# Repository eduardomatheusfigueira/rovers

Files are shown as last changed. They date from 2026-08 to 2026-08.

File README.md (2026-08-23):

# Rover Frugal 4WD/4WS
## UGV de baixo custo para logística predial — engenharia, simulação e gêmeo digital





> **Missão.** Desenvolver um Veículo Terrestre Não Tripulado capaz de buscar um
> notebook em qualquer ponto do Itaipu Parquetec e entregá-lo no departamento de
> T.I., **subindo escadas**, operado remotamente por um piloto — construído com
> tubos de PVC, impressão 3D, elásticos de escritório e eletrônica de prateleira.

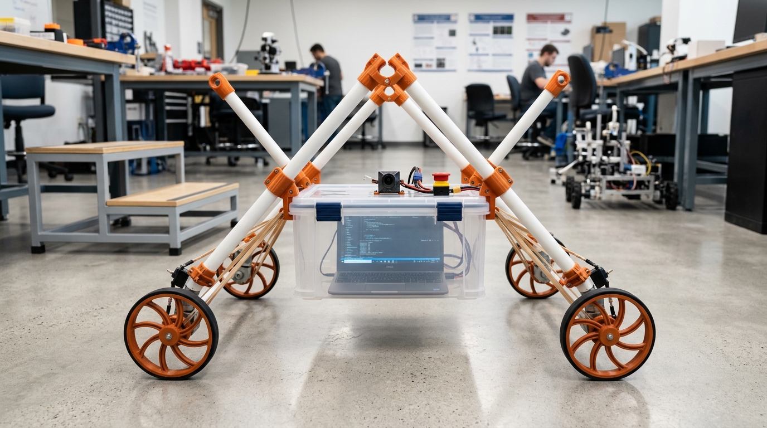
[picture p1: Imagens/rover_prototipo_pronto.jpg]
Protótipo do Rover Frugal


---

## Onde começar

| Se você quer... | Vá para |
| :--- | :--- |
| entender **as decisões de engenharia e por que mudaram** | [Auditoria Técnica R1→R2](00_Especificacao_Mestre/02_Auditoria_Tecnica.md) |
| ver **todos os números do projeto num lugar só** | [Parâmetros Mestres](00_Especificacao_Mestre/00_Parametros_Mestres.md) |
| saber **o que ainda falta provar** | [Requisitos e Rastreabilidade](00_Especificacao_Mestre/01_Requisitos_e_Rastreabilidade.md) |
| **pilotar** o rover num percurso simulado | [Gêmeo digital 3D](#gêmeo-digital-3d) |
| simular **física completa com ROS 2** | [Workspace ROS 2 / Gazebo](#ros-2-e-gazebo) |
| **rodar as contas** você mesmo | [Simulador Python](#simulador-físico-em-python) |
| avaliar a **proposta institucional** | [Pitch ao Parquetec](04_Proposta_Itaipu_Parquetec/01_Pitch_e_Plano_de_Apoio.md) |

---

## Estado do projeto

O projeto está na **Fase 2 — engenharia de detalhe e simulação**. Nenhuma peça
foi fabricada ainda. Isso importa para ler o resto do repositório:

* ✅ **18 requisitos** verificados por análise ou simulação automatizada;
* 🟡 **13 requisitos** verificados em simulação, aguardando ensaio físico;
* ⬜ **14 requisitos** dependem de hardware montado.

Todas as conclusões numéricas aqui são **previsões de modelo**, com domínio de
validade declarado em [Verificação e Validação](03_Simulacao_e_Prototipacao_Digital/04_Verificacao_e_Validacao_do_Modelo.md).

---

## O que a revisão R2 mudou no projeto

A engenharia foi reconstruída sobre uma fonte única de parâmetros e sobre modelos
sem fatores de ajuste. Cinco achados alteraram o projeto físico:

| Achado | R1 | R2 |
| :--- | :--- | :--- |
| **Diâmetro da roda** — a roda precisa alcançar o nariz do degrau seguinte, não apenas rolar | Φ300 mm (critério de rolamento em plano) | **Φ420 mm** por marcha síncrona e robustez de fase |
| **Aro elástico** — sem ele o cubo cai 105 mm por raio em piso plano | "opcional" | **item crítico** |
| **Curso da suspensão** — dimensionado pela energia da queda de cubo | 35 mm (4,2 g na carga) | **90 mm** (0,8 g) |
| **Rigidez do C-STS** — não se copia rigidez entre escalas | 0,55 N·m/rad (do artigo → 674° de deflexão) | **12,30 N·m/rad** por semelhança dimensional |
| **Classificação cinemática** | δm=2, δs=4, δM=3 (soma 6) | **δm=1, δs=2, δM=3** — não holonômico |

E a geração das malhas para o ROS 2 revelou um sétimo: **as rodas Φ420 pesam
2,55 kg, não os 1,80 kg orçados** — a massa total subiu para 10,03 kg e puxou
junto torque de projeto, rigidez do C-STS e margem de tração
([A-21](00_Especificacao_Mestre/02_Auditoria_Tecnica.md#a-21)). Todos os KPIs
continuam atendidos, com menos folga.

Mais dois limites operacionais que ninguém tinha visto:

* o gargalo da escada é **térmico**, não energético: 27 s de subida contínua antes
  do limite do enrolamento — a missão inteira usa só 15% da bateria;
* o rover **não sobe escada molhada**: exige μ ≥ 0,72 e o concreto úmido dá 0,55.

Cada achado está documentado com evidência reproduzível na
[Auditoria Técnica](00_Especificacao_Mestre/02_Auditoria_Tecnica.md).

---

## A ideia central, em uma equação

Uma roda de raios não rola sobre a escada — ela **salta de nariz em nariz**. Para
que o raio seguinte alcance o degrau seguinte:

$$\underbrace{\sqrt{E^2+P^2}}_{\text{passo do degrau}} \;\le\; 2\,r_{max}\sin\!\left(\frac{\pi}{N}\right)$$

Para o degrau de referência (E = 170 mm, P = 300 mm) e N = 3 raios:
**r_max ≥ 199 mm**. A roda de Φ300 mm alcança 260 mm contra 345 mm exigidos — e
por isso trava na face do espelho. A dedução completa está em
[Síntese da Roda](02_Engenharia_e_Arquitetura/06_Sintese_da_Roda_e_Geometria_de_Escalada.md).

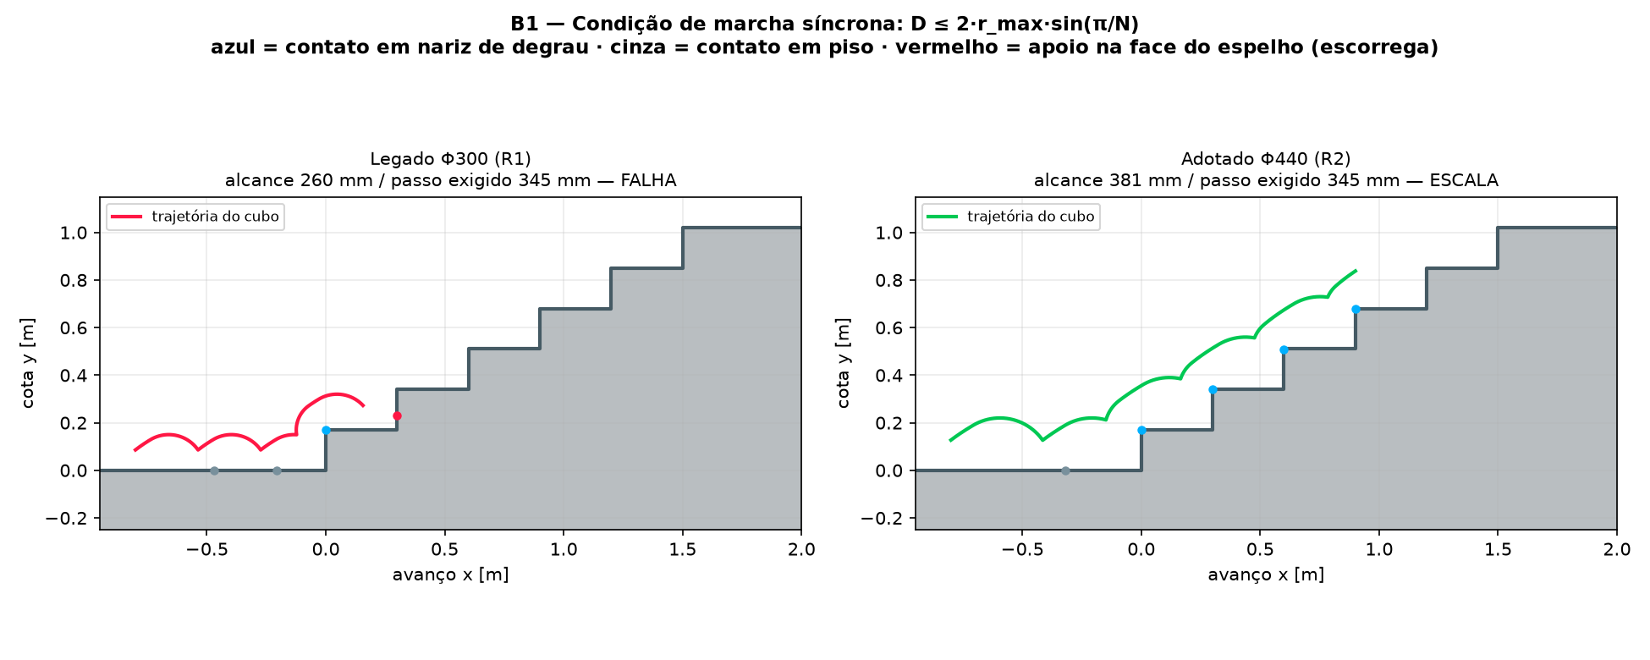
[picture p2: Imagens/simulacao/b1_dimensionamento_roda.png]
Comparação das duas rodas


---

## Como o repositório se sustenta

**Nenhum número de engenharia é digitado duas vezes.** Tudo vive em
[`parametros_mestres.yaml`](00_Especificacao_Mestre/parametros_mestres.yaml):

```
00_Especificacao_Mestre/parametros_mestres.yaml   ← fonte única de verdade
        │
        ├─→ simulador_python/config.py ────────── simulador, benchmarks, relatório
        ├─→ prototipo_3d/parametros.js ────────── gêmeo digital 3D
        └─→ 00_Parametros_Mestres.md ──────────── tabela da documentação
                                                  (os dois últimos são gerados)
```

Mudar o diâmetro da roda no YAML muda o simulador, o modelo 3D e a documentação
ao mesmo tempo. Testes automatizados verificam a coerência a cada alteração.

---

## Simulador físico em Python

```bash
pip install -r requirements.txt

python3 -m simulador_python.main --parametros   # configuração resolvida
python3 -m simulador_python.main --marcha       # marcha na escada de referência
python3 -m simulador_python.main --sintese      # varredura do espaço de projeto
python3 -m simulador_python.main --benchmark    # 6 benchmarks + figuras
python3 -m simulador_python.main --relatorio    # Relatório de Engenharia completo
python3 -m pytest testes/ -q                    # 73 verificações
```

| Módulo | O que resolve |
| :--- | :--- |
| [`geometria_escada.py`](simulador_python/geometria_escada.py) | marcha da roda de raios por **eventos de contato** — o núcleo do projeto |
| [`csts.py`](simulador_python/csts.py) | dimensionamento da mola espiral por semelhança dimensional e modelo de impacto |
| [`kinematics.py`](simulador_python/kinematics.py) | cinemática 4WS e classificação de Siegwart calculada por posto de matriz |
| [`terramechanics.py`](simulador_python/terramechanics.py) | cargas normais, estabilidade e comparação com skid-steer (Wong) |
| [`powertrain.py`](simulador_python/powertrain.py) | motor CC, redutor, bateria, modelo térmico e orçamento de missão |
| [`multibody_dynamics.py`](simulador_python/multibody_dynamics.py) | dinâmica sagital com a carga a bordo, alimentada pela marcha real |
| [`relatorio.py`](simulador_python/relatorio.py) | gera o Relatório de Engenharia — nenhum número é digitado à mão |

---

## Gêmeo digital 3D

Percurso completo de homologação — calçada, meio-fio, rampa, escadaria de 8
degraus, porta estreita e sala da T.I. — com física real de contato dos raios
curvos, C-STS integrada, bateria, modelo térmico e telemetria exportável.

```bash
# opção 1: arquivo único, duplo clique, sem servidor e sem internet
prototipo_3d_standalone.html

# opção 2: versão modular (recomendada para desenvolvimento)
python3 -m http.server 8000
# abrir http://localhost:8000/prototipo_3d/
```

O botão **"Comparar com a roda Φ300 (R1)"** reconstrói o rover com a geometria
original e reproduz a falha do achado A-01 na prática. As chaves de suspensão
ligam e desligam aro, elásticos e C-STS para ver o efeito de cada estágio na
aceleração sentida pelo notebook.

> Three.js r160 está versionado em `prototipo_3d/vendor/` (licença MIT): o
> protótipo **funciona offline**, sem depender de CDN.

---

## ROS 2 e Gazebo

Workspace completo em [`ros2_ws/`](ros2_ws/) — **ROS 2 Jazzy + Gazebo Harmonic**:

```bash
cd ros2_ws && colcon build --symlink-install && source install/setup.bash

ros2 launch rover_frugal_bringup missao.launch.py            # percurso completo
ros2 launch rover_frugal_bringup ensaio_escada.launch.py     # ensaio instrumentado
ros2 launch rover_frugal_description visualizar.launch.py    # só a geometria, no RViz
```

| Pacote | Conteúdo |
| :--- | :--- |
| `rover_frugal_description` | URDF/xacro **sem nenhum número** — lê `config/parametros.yaml`, gerado do arquivo mestre; malhas STL geradas do mesmo perfil de raio da física |
| `rover_frugal_control` | cinemática 4WS, tração com a curva real do motorredutor, molas passivas (suspensão e C-STS), supervisor de segurança |
| `rover_frugal_gazebo` | mundos SDF gerados dos parâmetros, ponte `ros_gz`, launch |
| `rover_frugal_bringup` | missão, ensaios, registrador de telemetria |

Três decisões de modelagem que valem destaque — todas detalhadas em
[`03_Simulacao/05`](03_Simulacao_e_Prototipacao_Digital/05_ROS2_e_Gazebo.md):

* **O casco convexo de uma roda de raios é um disco.** Usar a malha como colisão
  faria o motor de física apagar silenciosamente a geometria de raios — e a
  simulação escalaria escadas que na prática são impossíveis. A colisão é uma
  cadeia de 81 esferas por roda, com sobreposição garantida.
* **O aro elástico não colapsa em corpo rígido**, então o modelo tem duas
  variantes (`aro_elastico:=true|false`) e a limitação é declarada.
* **As molas passivas ficam num nó ROS, não no SDF** — o que as torna portáteis e
  impõe um requisito explícito de 1000 Hz na malha de controle.
* **A tração é comandada por esforço, não por velocidade.** Com interface de
  velocidade o motor simulado teria torque de stall a 1,53 m/s e o rover subiria
  escadas que o motorredutor real não sustenta — a margem de torque de 1,61
  jamais seria exercida pela simulação.

74 testes validam o pacote **sem ROS instalado** (`xacro` e `yourdfpy` do PyPI):
massa, inércias, cinemática direta, limites de junta, geometria de colisão, a
escada do mundo e o passo de integração. A cinemática do nó ROS é comparada com a
do simulador a cada execução — divergência de 8,9 × 10⁻¹⁶ rad, contra os 0,1° que
o ensaio ENS-01 admite.

---

## Mapa da documentação

```mermaid
graph TD
    M["00. Especificação Mestre<br/><i>fonte única de verdade</i>"]
    M --> M1["Parâmetros Mestres<br/><i>gerado</i>"]
    M --> M2["Requisitos e Rastreabilidade"]
    M --> M3["Auditoria Técnica R1→R2"]

    P1["01. Planejamento Geral"] --> P1a["Escopo · Fases · PMBOK 7 · Critérios"]
    P2["02. Engenharia e Arquitetura"] --> P2a["Mecânica · Rodas · 4WD/4WS · Eletrônica"]
    P2 --> P2b["<b>06. Síntese da Roda</b><br/>07. Tração e Térmica<br/>08. Firmware<br/>09. FMEA"]
    P3["03. Simulação"] --> P3a["CAD · Dinâmica · Gêmeo Digital"]
    P3 --> P3b["<b>04. Verificação e Validação</b>"]
    P4["04. Proposta Parquetec"] --> P4a["Pitch · Equipe · Orçamento"]
    P5["05. Execução e Testes"] --> P5a["Montagem · Ensaios · Missão"]
    P6["06. Roadmap Futuro"] --> P6a["Fase A longo alcance · Fase B uso dual"]

    M --> P1 & P2 & P3 & P4 & P5 & P6
```

### Índice

**[00. Especificação Mestre](00_Especificacao_Mestre/)** — fonte única de verdade
* [`parametros_mestres.yaml`](00_Especificacao_Mestre/parametros_mestres.yaml) — todos os números do projeto
* [00. Parâmetros Mestres](00_Especificacao_Mestre/00_Parametros_Mestres.md) *(gerado)* — tabela e verificações de coerência
* [01. Requisitos e Rastreabilidade](00_Especificacao_Mestre/01_Requisitos_e_Rastreabilidade.md) — 45 requisitos com método de verificação
* [02. Auditoria Técnica](00_Especificacao_Mestre/02_Auditoria_Tecnica.md) — 20 achados de R1 com evidência e resolução

**[01. Planejamento Geral](01_Planejamento_Geral/)**
* [01. Visão Geral e Escopo](01_Planejamento_Geral/01_Visao_Geral_e_Escopo.md) · [02. Fases e Cronograma](01_Planejamento_Geral/02_Estrutura_Fases_e_Cronograma.md) · [03. Gestão e PMBOK 7](01_Planejamento_Geral/03_Gestao_e_PMBOK7.md) · [04. Critérios de Sucesso](01_Planejamento_Geral/04_Criterios_de_Sucesso_e_Validacao.md)

**[02. Engenharia e Arquitetura](02_Engenharia_e_Arquitetura/)**
* [01. Arquitetura Mecânica](02_Engenharia_e_Arquitetura/01_Arquitetura_Mecanica_e_Geometria.md) · [02. Rodas e Suspensão](02_Engenharia_e_Arquitetura/02_Rodas_Curved_Spokes_e_Suspensao.md) · [03. Tração 4WD e Direção 4WS](02_Engenharia_e_Arquitetura/03_Tracao_4WD_e_Direcao_4WS.md) · [04. Eletrônica e Potência](02_Engenharia_e_Arquitetura/04_Eletronica_Controle_e_Potencia.md) · [05. Blondel e Colisão](02_Engenharia_e_Arquitetura/05_Dimensionamento_Blondel_e_Dinamica_Colisao.md)
* **[06. Síntese da Roda e Geometria de Escalada](02_Engenharia_e_Arquitetura/06_Sintese_da_Roda_e_Geometria_de_Escalada.md)** — documento central de R2
* **[07. Tração, Energia e Térmica](02_Engenharia_e_Arquitetura/07_Orcamento_de_Tracao_Energia_e_Termica.md)**
* **[08. Firmware e Segurança Funcional](02_Engenharia_e_Arquitetura/08_Arquitetura_de_Firmware_e_Seguranca_Funcional.md)**
* **[09. FMEA](02_Engenharia_e_Arquitetura/09_FMEA_e_Analise_de_Falhas.md)**

**[03. Simulação e Prototipação Digital](03_Simulacao_e_Prototipacao_Digital/)**
* [01. Modelagem CAD 3D](03_Simulacao_e_Prototipacao_Digital/01_Plano_de_Modelagem_CAD_3D.md) · [02. Simulação Dinâmica](03_Simulacao_e_Prototipacao_Digital/02_Simulacao_Dinamica_e_Controle.md) · [03. Gêmeo Digital](03_Simulacao_e_Prototipacao_Digital/03_Ambiente_Virtual_e_Digital_Twin.md)
* **[04. Verificação e Validação do Modelo](03_Simulacao_e_Prototipacao_Digital/04_Verificacao_e_Validacao_do_Modelo.md)**
* **[05. Simulação Multicorpo em ROS 2 e Gazebo](03_Simulacao_e_Prototipacao_Digital/05_ROS2_e_Gazebo.md)**

**[04. Proposta Itaipu Parquetec](04_Proposta_Itaipu_Parquetec/)**
* [01. Pitch e Plano de Apoio](04_Proposta_Itaipu_Parquetec/01_Pitch_e_Plano_de_Apoio.md) · [02. Equipe e Infraestrutura](04_Proposta_Itaipu_Parquetec/02_Alocacao_Equipe_e_Infraestrutura.md) · [03. Orçamento e Aporte](04_Proposta_Itaipu_Parquetec/03_Orcamento_e_Aporte_Proprio_1k_USD.md)

**[05. Execução, Testes e Operação](05_Execucao_Testes_e_Operacao/)**
* [01. Roteiro de Montagem](05_Execucao_Testes_e_Operacao/01_Roteiro_de_Montagem_e_Modularidade.md) · [02. Protocolo de Testes](05_Execucao_Testes_e_Operacao/02_Protocolo_de_Testes_e_Iteracoes.md) · [03. Missão de Homologação](05_Execucao_Testes_e_Operacao/03_Missao_Operacional_Parquetec_TI.md)

**[06. Roadmap Futuro](06_Roadmap_Futuro_Fases_Pos_Sucesso/)**
* [01. Fase A — Longo Alcance](06_Roadmap_Futuro_Fases_Pos_Sucesso/01_Fase_A_Extensao_Distancias_e_Ambientes_Reais.md) · [02. Fase B — Uso Dual e Fibra Óptica](06_Roadmap_Futuro_Fases_Pos_Sucesso/02_Fase_B_Uso_Dual_e_Controle_Fibra_Optica.md)

---

## Base teórica

| Obra | O que este projeto usa |
| :--- | :--- |
| **Siegwart & Nourbakhsh (2004)**, *Introduction to Autonomous Mobile Robots* | restrições de rolamento e deslizamento, grau de manobrabilidade (Tabela 3.1), odometria, margem de estabilidade |
| **J. Y. Wong (2022)**, *Theory of Ground Vehicles* | transferência de carga em rampa, esforço trativo, resistência ao rolamento, momento resistente de derrapagem |
| **Sclater & Chironis (2001)**, *Mechanisms and Mechanical Devices Sourcebook* | abraçadeiras bipartidas, presilhas toggle over-center, tensores elásticos com batente |
| **Jeong & Kim (2025)**, *Appl. Sci.* 15, 5985 | roda de raios curvos, suspensão complacente torsional C-STS, fator de correção FDM |
| **Blondel (1675)** e **ABNT NBR 9050** | 2E + P = 63 a 65 cm — a geometria de escada que define o projeto da roda |
| **PMBOK 7ª edição** | princípios de entrega de valor e domínios de desempenho |

Os originais estão em [`Materiais de apoio`](<Materiais de apoio>).

---

## Ferramentas de manutenção do repositório

```bash
python3 ferramentas/gerar_parametros_js.py   # YAML → prototipo_3d/parametros.js
python3 ferramentas/gerar_documentacao.py    # YAML → 00_Parametros_Mestres.md
python3 ferramentas/gerar_standalone.py      # prototipo_3d/ → HTML único offline
python3 ferramentas/gerar_malhas.py          # YAML → malhas STL do pacote ROS
python3 ferramentas/gerar_ros_config.py      # YAML → parametros.yaml + controladores.yaml
python3 ferramentas/gerar_mundo_gazebo.py    # YAML → mundos SDF do Gazebo
python3 ferramentas/gerar_figuras.py         # figuras citadas na documentação
```

Rode todos sempre que alterar `parametros_mestres.yaml` — a integração contínua
reprova o commit se algum artefato ficar fora de sincronia.

---

## Licença

**Ainda não definida.** O projeto declara intenção de ser aberto (Open Hardware /
Open Source) em `01_Planejamento_Geral/02`, mas a escolha da licença é decisão do
proponente e precisa ser combinada com o Itaipu Parquetec antes da publicação dos
CADs. Sugestão para avaliação: **CERN-OHL-S v2** para o hardware e **Apache-2.0**
ou **MIT** para o firmware e o simulador.

Three.js (`prototipo_3d/vendor/three/`) é distribuído sob licença MIT — ver
[LICENSE-three.txt](prototipo_3d/vendor/three/LICENSE-three.txt).

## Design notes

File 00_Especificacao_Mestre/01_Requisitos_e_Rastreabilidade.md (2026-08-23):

# 01. Requisitos de Engenharia e Matriz de Rastreabilidade

> **Para que serve.** Em R1 os critérios de sucesso estavam numa tabela e os
> ensaios em outra, sem vínculo — não era possível responder "qual evidência
> prova este requisito?". Aqui cada requisito tem identificador, valor,
> **método de verificação** e **artefato de evidência**.
>
> **Métodos de verificação** (convenção clássica de engenharia de sistemas):
> **A** análise · **S** simulação · **E** ensaio · **D** demonstração · **I** inspeção.
>
> **Situação:** ✅ verificado · 🟡 verificado em simulação, pendente de ensaio ·
> ⬜ pendente · ➖ fora do escopo desta fase.

---

## 1. Requisitos de missão (nível de sistema)

| ID | Requisito | Valor | Verif. | Evidência | Situação |
| :--- | :--- | :--- | :---: | :--- | :---: |
| **REQ-001** | Transportar carga útil de notebook + fonte | ≥ 2,5 kg (meta 3,0) | E | ENS-08 (pesagem + missão com carga) | ⬜ |
| **REQ-002** | Transpor degraus de escada civil padrão | E ≤ 180 mm, P ≥ 280 mm | S+E | `b1_dimensionamento_roda.png`, ENS-06 | 🟡 |
| **REQ-003** | Velocidade em terreno plano | ≥ 0,5 m/s (meta 1,0) | S+E | `b5_tracao.png`, ENS-03 | 🟡 |
| **REQ-004** | Choque vertical máximo na carga | ≤ 2,0 g (meta 1,5) | S+E | `b2_b3_suspensao.png`, ENS-07 | 🟡 |
| **REQ-005** | Autonomia em ciclo misto | ≥ 30 min (meta 45) | A+E | Relatório §4.1, ENS-09 | 🟡 |
| **REQ-006** | Alcance do enlace de teleoperação | ≥ 150 m NLOS (meta 300) | E | ENS-10 | ⬜ |
| **REQ-007** | Substituição de peça crítica | ≤ 15 min (meta 10) | D | Roteiro de montagem, DEM-02 | ⬜ |
| **REQ-008** | Custo de materiais novos | ≤ US$ 1.000 | I | Prestação de contas | ⬜ |
| **REQ-009** | Transpor porta e corredor estreitos | vão ≥ 800 mm | S+D | Gêmeo digital, DEM-03 | 🟡 |
| **REQ-010** | Integridade funcional da carga após transporte | boot normal, sem dano | D | Ata de homologação | ⬜ |

---

## 2. Requisitos de locomoção e geometria

| ID | Requisito | Valor | Verif. | Evidência | Situação |
| :--- | :--- | :--- | :---: | :--- | :---: |
| **REQ-101** | Marcha síncrona na escada de referência | D ≤ 2·r_max·sin(π/N) | A | `test_alcance_nariz_a_nariz_bate_com_a_formula` | ✅ |
| **REQ-102** | Escalar a partir de qualquer fase de aproximação | 100% das fases | S | `test_roda_adotada_escala_toda_a_familia_de_blondel` | ✅ |
| **REQ-103** | Cobrir a família de escadas de Blondel | E de 160 a 180 mm | S | Auditoria A-01, tabela de robustez | ✅ |
| **REQ-104** | Vão livre do ventre acima do espelho | ≥ E + 20 mm | A | `test_vao_livre_supera_o_espelho` | ✅ |
| **REQ-105** | Fase travada entre eixos na escada | L = k·D | A | `test_entre_eixos_e_multiplo_do_passo_do_degrau` | ✅ |
| **REQ-106** | Margem de tombamento longitudinal na escada | ≥ 10° | A | `test_margem_de_tombamento_atende_ao_kpi` | ✅ |
| **REQ-107** | Giro no próprio eixo dentro do curso dos servos | β ≤ 55° | A | `test_giro_no_eixo_cabe_no_curso_dos_servos` | ✅ |
| **REQ-108** | Ausência de arrasto lateral em 4WS coordenado | resíduo < 1e-9 m/s | A | `test_sem_arrasto_lateral` | ✅ |
| **REQ-109** | Rolamento em piso plano sem ripple destrutivo | ripple ≤ 10 mm | S | `test_aro_elastico_e_indispensavel_em_piso_plano` | ✅ |
| **REQ-110** | Transpor meio-fio urbano | ≥ 150 mm | S+E | `test_meio_fio_e_transposto`, ENS-05 | 🟡 |

---

## 3. Requisitos de suspensão e estrutura

| ID | Requisito | Valor | Verif. | Evidência | Situação |
| :--- | :--- | :--- | :---: | :--- | :---: |
| **REQ-201** | Curso da suspensão absorve a queda da marcha | ≥ 90 mm | A+S | `test_curso_da_suspensao_cobre_a_queda_da_marcha` | ✅ |
| **REQ-202** | Afundamento estático dentro da boa prática | 20 a 30% do curso | A | Parâmetros mestres §3 | ✅ |
| **REQ-203** | C-STS dimensionada para o torque de projeto | Δθ ≤ 35° em T_max | A | `test_rigidez_de_projeto_bate_com_torque_sobre_deflexao` | ✅ |
| **REQ-204** | Tensão de flexão na espiral C-STS | FS ≥ 2,0 | A | `test_espiral_cabe_no_cubo_e_tem_fator_de_seguranca` | ✅ |
| **REQ-205** | Espiral C-STS cabe dentro do cubo | r_ext < r_cubo | A | idem | ✅ |
| **REQ-206** | Pêndulo da caixa é estável | CG abaixo da fixação | A | `test_pendulo_e_estavel` | ✅ |
| **REQ-207** | Aro elástico colapsa na quina liberando o raio | F_colapso ≈ 90 N | E | ENS-04 (bancada) | ⬜ |
| **REQ-208** | Vida em fadiga do feixe de elásticos | ≥ 50 ciclos, deformação residual < 15% | E | ENS-11 | ⬜ |
| **REQ-209** | Raio curvo suporta a carga de ponta | FS ≥ 3,0 | A+E | Análise de viga, ENS-12 | 🟡 |
| **REQ-210** | Troca de caixa organizadora sem ferramenta | ≤ 2 min | D | DEM-02 | ⬜ |

---

## 4. Requisitos de tração, energia e térmica

| ID | Requisito | Valor | Verif. | Evidência | Situação |
| :--- | :--- | :--- | :---: | :--- | :---: |
| **REQ-301** | Margem de torque no pior caso de escada | ≥ 1,50 | A | `test_margem_de_torque_na_escada_atende_ao_kpi` | ✅ |
| **REQ-302** | Missão completa cabe na energia útil | ≤ 80% do pack | A | `test_missao_cabe_na_energia_util` | ✅ |
| **REQ-303** | Célula suporta a corrente de pico | ≥ 5C contínuo | I | Datasheet da célula adotada | ⬜ |
| **REQ-304** | Proteção térmica impede dano ao enrolamento | corte antes de 115 °C | A+E | `test_limite_termico...`, ENS-13 | 🟡 |
| **REQ-305** | Pausa de resfriamento entre lances de escada | imposta pelo firmware | I+D | Revisão de código, DEM-04 | ⬜ |
| **REQ-306** | Atrito disponível cobre a escada seca | μ ≥ 0,72 | A+E | `test_atrito_disponivel...`, ENS-06 | 🟡 |
| **REQ-307** | Frenagem em rampa sem deriva | parada em ≤ 0,5 m | E | ENS-14 | ⬜ |

---

## 5. Requisitos de controle, segurança e teleoperação

| ID | Requisito | Valor | Verif. | Evidência | Situação |
| :--- | :--- | :--- | :---: | :--- | :---: |
| **REQ-401** | Failsafe por perda de enlace | motores parados em ≤ 300 ms | E | ENS-10 | ⬜ |
| **REQ-402** | Limiar anti-tombamento por modo | 35° piso / 52° escada | I+S | Firmware, gêmeo digital | 🟡 |
| **REQ-403** | Calibração dos servos 4WS | erro ≤ 1,0° por servo | E | ENS-02 | ⬜ |
| **REQ-404** | Odometria compensa a complacência do C-STS | erro ≤ 5% em 10 m | A+E | `02_Engenharia/08`, ENS-15 | ⬜ |
| **REQ-405** | Frequência da malha de controle | ≥ 200 Hz | I | Revisão de firmware | ⬜ |
| **REQ-406** | Latência do vídeo FPV | ≤ 50 ms | E | ENS-10 | ⬜ |
| **REQ-407** | Parada de emergência independente do enlace | acionável no veículo | I+D | Inspeção, DEM-05 | ⬜ |
| **REQ-408** | Registro de telemetria da missão | ≥ 20 Hz, exportável | D | Gêmeo digital (CSV), ENS-16 | 🟡 |

---

## 5b. Requisitos de simulação e gêmeo digital

| ID | Requisito | Valor | Verif. | Evidência | Situação |
| :--- | :--- | :--- | :---: | :--- | :---: |
| **REQ-501** | Descrição do robô sem números duplicados | URDF lê o arquivo mestre | A | `test_massa_total_bate_com_o_arquivo_mestre` | ✅ |
| **REQ-502** | Inércias fisicamente admissíveis | positivas-definidas, desigualdade triangular | A | `test_inercias_positivas_definidas` | ✅ |
| **REQ-503** | Colisão preserva a geometria de raios | primitivas, não casco convexo | A | `test_variante_sem_aro_usa_cadeia_de_esferas` | ✅ |
| **REQ-504** | Cadeia de colisão sem lacunas | sobreposição ≥ 85% | A | `test_esferas_cobrem_o_raio_sem_buracos` | ✅ |
| **REQ-505** | Encalhe do ventre é detectável em simulação | colisão na cota do vão livre | A | `test_ventre_tem_colisao` | ✅ |
| **REQ-506** | Escada simulada = escada de projeto | E e P do arquivo mestre | A | `test_escada_do_mundo_e_a_escada_do_projeto` | ✅ |
| **REQ-507** | Passo de integração resolve o contato | ω·Δt < 0,5 | A | `test_passo_de_integracao_resolve_o_contato` | ✅ |
| **REQ-508** | Malha de juntas passivas mais rápida que a dinâmica | ≥ 20·√(k/m) | A | `controladores.yaml` (1000 Hz) | ✅ |
| **REQ-509** | Cinemática do nó ROS = referência analítica | ≤ 0,1° e 1 mm/s (ENS-01) | A | `test_no_ros_bate_com_o_simulador` | ✅ |
| **REQ-510** | Malhas imprimíveis | sem furos, volume positivo | A | `test_malhas_nao_tem_furos` | ✅ |
| **REQ-511** | Massa declarada reflete a geometria real | ±20% do volume das malhas | A | `test_massa_das_rodas_bate_com_as_malhas` | ✅ |
| **REQ-512** | Telemetria de simulação = telemetria do firmware | mesmas colunas | I | `registrador.py` × `02_Engenharia/08` §5 | ✅ |
| **REQ-513** | Supervisor não aborta subida normal | 43° em escada é operação | A | `test_arfagem_normal_de_escada_nao_dispara_protecao` | ✅ |
| **REQ-514** | Modo escada bloqueado sem piso seco | confirmação explícita | A | `test_modo_escada_bloqueado_sem_confirmar_piso_seco` | ✅ |
| **REQ-515** | Rearme após failsafe é sempre explícito | nunca automático | A | `test_rearme_e_sempre_explicito` | ✅ |
| **REQ-516** | Validação do modelo contra ensaio físico | ±40% no pico de aceleração | S+E | ENS-06 | ⬜ |
| **REQ-517** | Motor simulado = motor dimensionado | curva ponto a ponto | A | `test_motor_do_no_ros_bate_com_o_dimensionamento` | ✅ |
| **REQ-518** | Torque disponível cai com a rotação | monotônico até zero em ω₀ | A | `test_torque_cai_com_a_rotacao` | ✅ |
| **REQ-519** | Controle de tração satura no torque físico | não em limite arbitrário | A | `test_controle_satura_no_torque_disponivel` | ✅ |
| **REQ-520** | Anti-windup no PI de tração | integrador limitado sob saturação | A | `test_anti_windup_evita_disparo_apos_saturacao` | ✅ |
| **REQ-521** | Contato da roda observável por sensor | pontas nomeadas, tópico `/contatos` | A | `test_sensor_de_contato_existe_nas_duas_variantes` | ✅ |
| **REQ-522** | Odometria de verdade-terreno disponível | plugin de odometria no modelo | A | `test_odometria_de_verdade_terreno_publicada` | ✅ |

---

## 6. Rastreabilidade inversa: de onde veio cada requisito

```mermaid
graph LR
    subgraph Fontes
        NBR["ABNT NBR 9050<br/>Blondel 2E+P = 64 cm"]
        SIEG["Siegwart & Nourbakhsh (2004)<br/>cinemática e estabilidade"]
        WONG["J. Y. Wong (2022)<br/>terramecânica e cargas"]
        JEONG["Jeong & Kim (2025)<br/>C-STS e raios curvos"]
        SCLA["Sclater & Chironis (2001)<br/>mecanismos de fixação"]
        MISSAO["Missão de homologação<br/>Parquetec / T.I."]
    end

    NBR --> R102["REQ-002, 101 a 105"]
    SIEG --> R107["REQ-106 a 108, 402"]
    WONG --> R301["REQ-301, 306, 307"]
    JEONG --> R203["REQ-203 a 205, 209"]
    SCLA --> R210["REQ-007, 210"]
    MISSAO --> R001["REQ-001, 003 a 010"]
```

---

## 7. Estado consolidado

| Situação | Quantidade | Observação |
| :--- | ---: | :--- |
| ✅ Verificado por análise/simulação automatizada | 39 | cobertos por 156 testes automatizados |
| 🟡 Verificado em simulação, pendente de ensaio físico | 13 | dependem da Fase 4 |
| ⬜ Pendente | 15 | dependem de hardware montado |

> **Regra de encerramento de fase.** A Fase 2 (engenharia e simulação) só se
> encerra com todos os requisitos de nível A/S em ✅. A Fase 5 (homologação) só se
> encerra com todos os requisitos de missão em ✅.

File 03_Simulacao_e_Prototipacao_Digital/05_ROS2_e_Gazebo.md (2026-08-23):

# 05. Simulação Multicorpo em ROS 2 e Gazebo
## Do URDF ao contato: o que é difícil de simular numa roda de raios curvos

> **Situação anterior.** `02_Simulacao_Dinamica_e_Controle` prometia "modelagem
> multicorpo (URDF/SDF)" em "Webots/Gazebo", e `03_Ambiente_Virtual` prometia um
> gêmeo digital do Parquetec. Não existia nenhum URDF, nenhum mundo, nenhum
> pacote — apenas a intenção. Este documento descreve a implementação real, em
> [`ros2_ws/`](../ros2_ws/), e as decisões de modelagem que ela exigiu.

**Alvo:** ROS 2 **Jazzy Jalisco** (LTS) com **Gazebo Harmonic** (`gz-sim` 8) e
`gz_ros2_control`.

---

## 1. Por que Gazebo, e não Webots

| Critério | Gazebo (gz-sim) | Webots |
| :--- | :--- | :--- |
| Integração com ROS 2 | nativa (`ros_gz`, `gz_ros2_control`) | via `webots_ros2`, com camada extra |
| Motor de física | DART, com molas e amortecimento em junta | ODE próprio |
| Contato com muitas primitivas | maduro; a marcha de raios exige centenas de esferas | funcional, menos usado nesse regime |
| Descrição do robô | SDF, com conversão direta de URDF | PROTO próprio, sem URDF nativo |
| Reprodutibilidade em CI | headless simples (`-s -r`) | exige display virtual |

A decisão pesa sobretudo o **URDF nativo** e o `ros2_control`: o mesmo arquivo de
descrição alimenta RViz, o Gazebo e — depois — o `ros2_control` do hardware real.
A menção a Webots foi removida dos documentos para não sugerir duas cadeias
paralelas de ferramentas.

---

## 2. Onde o Gazebo entra na hierarquia de modelos

```mermaid
graph LR
    A["<b>Modelo geométrico de marcha</b><br/>simulador_python/geometria_escada.py<br/>quase-estático, por eventos"]
    B["<b>Modelo dinâmico sagital</b><br/>simulador_python/multibody_dynamics.py<br/>7 GDL, passo fixo"]
    C["<b>Gazebo + ROS 2</b><br/>ros2_ws/<br/>3D, contato completo, controle real"]
    D["<b>Gêmeo digital 3D</b><br/>prototipo_3d/<br/>tempo real, pilotagem"]

    A -->|"trajetória do cubo"| B
    A -->|"perfil dos raios"| C
    A -->|"perfil dos raios"| D
    B -->|"valores de referência"| C

    C --> R["Autoridade sobre:<br/>manobra 3D, aproximação oblíqua,<br/>integração de software,<br/>comportamento do controlador"]
```

> **O Gazebo não substitui o modelo analítico.** Para viabilidade de escalada e
> torque de içamento, quem manda é o modelo geométrico (`03_Simulacao/04`, §1).
> O Gazebo responde ao que o modelo sagital **não** cobre: manobra em três
> dimensões, aproximação oblíqua da escada, e — o mais importante — se o
> **software de controle** funciona.

---

## 3. Estrutura do workspace

```
ros2_ws/src/
├── rover_frugal_description/   URDF/xacro, malhas STL, RViz
│   ├── config/parametros.yaml      ← GERADO do arquivo mestre
│   ├── meshes/*.stl                ← GERADAS do mesmo perfil de raio da física
│   └── urdf/rover_frugal.urdf.xacro   escrito à mão, SEM nenhum número
├── rover_frugal_control/       cinemática 4WS, tração, molas passivas, supervisor
├── rover_frugal_gazebo/        mundos SDF (gerados), ponte ros_gz, launch
└── rover_frugal_bringup/       missão, ensaios, registrador de telemetria
```

A cadeia de geração fecha o mesmo princípio do resto do repositório:

```
parametros_mestres.yaml
   ├─→ gerar_malhas.py        → meshes/*.stl
   ├─→ gerar_ros_config.py    → config/parametros.yaml + controladores.yaml
   └─→ gerar_mundo_gazebo.py  → worlds/*.sdf
```

**O xacro não contém um único número de engenharia.** Ele carrega o YAML com
`xacro.load_yaml` e monta o robô a partir dele. Trocar o diâmetro da roda no
arquivo mestre muda a malha, a inércia, a colisão, os limites de junta, os ganhos
do controlador e a escada do mundo — de uma vez.

---

## 4. As cinco decisões difíceis

### 4.1. A cadeia cinemática tem quatro juntas por roda, nessa ordem

```
base_link
  └─ suporte_i   ← prismática  susp_i     PASSIVA · mola 1000 N/m · curso 90 mm
       └─ manga_i     ← revoluta  esterco_i  ATUADA · servo 4WS · ±55°
            └─ cubo_i      ← contínua  tracao_i   ATUADA · motorredutor 1:172
                 └─ roda_i      ← revoluta  csts_i     PASSIVA · mola 12,3 N·m/rad
```

A ordem não é arbitrária e **não pode ser simplificada**: a suspensão fica entre
o braço e a manga, o esterçamento gira a manga inteira (com motor e roda), o
motor aciona o cubo, e o C-STS fica **entre o cubo e a roda**. Colapsar o C-STS
apagaria justamente o elemento que o projeto adota de Jeong & Kim (2025); colocá-lo
antes do motor faria a mola trabalhar contra o esterçamento em vez do torque.

São 16 juntas móveis: 8 atuadas e 8 passivas.

### 4.2. Molas passivas ficam num nó ROS, não no SDF

`<spring_stiffness>` existe em SDF mas **depende do motor de física** (DART
aplica, ODE ignora) e não existe em URDF. A lei de mola vive em
`rover_frugal_control/molas_passivas.py`, aplicada por um
`effort_controllers/JointGroupEffortController`:

$$F_{susp} = -k\,x - c\,\dot{x} \;(+ \text{batente}), \qquad
\tau_{C\text{-}STS} = -k_t\,\theta - c_t\,\dot{\theta} \;(+ \text{batente})$$

Três consequências que o projeto ganha com isso:

1. **Portabilidade.** A mesma lei roda no Gazebo, em qualquer outro simulador e —
   se um dia houver suspensão semiativa — no hardware.
2. **Constantes idênticas às do dimensionamento.** `k = 1000 N/m` e
   `kt = 12,3 N·m/rad` vêm do mesmo arquivo mestre que dimensionou a mola.
3. **Requisito de taxa explícito.** A malha precisa ser bem mais rápida que a
   frequência natural mais alta: com $k$ = 1000 N/m e massa não suspensa de
   0,64 kg, $\omega = \sqrt{k/m} \approx 40$ rad/s. O gerador calcula o mínimo
   (**792 Hz**) e o `controller_manager` roda a **1000 Hz**. Simular molas a
   100 Hz — a taxa "natural" de um nó ROS — produziria oscilação numérica que
   pareceria dinâmica real.

### 4.3. O casco convexo de uma roda de raios é um disco

Este é o ponto mais delicado da simulação. Se a colisão da roda for a malha STL,
DART e ODE usam o **casco convexo** — que para uma roda de três raios é
simplesmente um **disco**. A simulação rodaria linda e escalaria qualquer escada,
porque a geometria de raios de que todo o projeto depende teria sido apagada
silenciosamente pelo motor de física.

A colisão é, portanto, feita de **primitivas**: uma cadeia de esferas segue a
linha média de cada raio, com espaçamento adaptativo que garante sobreposição.

| | Variante `aro_elastico:=true` | Variante `aro_elastico:=false` |
| :--- | :--- | :--- |
| Colisão da roda | 1 cilindro em $r_{max}$ | **81 esferas** (27 por raio) |
| Rigidez de contato | $k_p$ = 3500 N/m (= rigidez do aro) | $k_p$ = 10⁵ N/m (pastilha sobre PETG) |
| Uso | percurso, piso plano, manobra | marcha em escada, engate no nariz |

O espaçamento é resolvido por caminhada adaptativa: uma esfera nova só é aceita
quando ainda houver **85% de sobreposição** com a anterior. Espaçar demais faria
o nariz do degrau "passar entre" as esferas e a roda atravessaria a quina —
falha silenciosa e difícil de diagnosticar olhando a animação.

### 4.4. O aro elástico não colapsa em corpo rígido

O aro funciona porque **colapsa localmente** na quina do degrau, expondo a ponta
do raio. Nenhum motor de física de corpos rígidos representa isso: um toro rígido
rolaria por cima do degrau.

A solução honesta é **duas variantes do modelo**, e dizer isso em voz alta:

* **com aro** — cilindro em $r_{max}$ com contato mole ($k_p$ = 3500 N/m, a
  própria rigidez radial do aro). Sob $W/4$ = 24,6 N a roda afunda 7,0 mm,
  exatamente o que o modelo analítico prevê. E porque a complacência está no
  **contato** e não no raio, o afundamento responde à carga em vez de ser fixo;
* **sem aro** — raios expostos, contato rígido, marcha de escada real.

A transição entre os dois regimes — o colapso local — é o que o modelo Python
trata e o Gazebo não. Ela é também o maior risco técnico em aberto do projeto
(F-01 na FMEA) e o objeto do ensaio ENS-04.

### 4.5. Tração por esforço, com a curva real do motorredutor

Se a tração for comandada por **velocidade**, o `ros2_control` pede a rotação e o
Gazebo entrega qualquer torque até o limite da junta. O motor simulado teria
**torque de stall a 1,53 m/s** — fisicamente impossível — e o rover subiria
escadas que o motorredutor real não sustenta. A margem de torque de 1,61 nunca
seria testada: a simulação simplesmente não a exerceria.

Por isso a interface de tração é de **esforço**, e o nó `tracao` faz a conversão:

```
velocidade desejada de roda ──►  PI de velocidade
                                      │
                        saturado pelo torque que o motorredutor
                        CONSEGUE entregar naquela rotação e tensão
                                      │
                                      ▼
                          esforço → tracao_controller
```

Três limites da análise passam a valer dentro do simulador:

| Limite | Como entra |
| :--- | :--- |
| Curva torque-velocidade | $T(\omega) = K_t\,(I - I_0)\,i\,\eta$ com $I = (V - K_e\omega i)/R_a$ |
| Queda de tensão do pack | 28,6 A de pico sobre 50 mΩ derrubam a tensão e, com ela, o torque |
| Limite térmico | modelo I²t por motor; ao atingir 115 °C o fator de torque daquela roda vai a zero |

O PI tem **anti-windup**: sem ele o integrador carrega durante a saturação na
escada e o rover dispara quando a roda finalmente engata — um artefato que
pareceria "o rover pulou o degrau".

Um teste garante que o motor simulado é o motor dimensionado, ponto a ponto da
curva: `test_motor_do_no_ros_bate_com_o_dimensionamento`.

### 4.6. Massa e inércia vêm das malhas, não de estimativa

O gerador de malhas calcula o volume de material de cada peça — considerando
preenchimento real de impressão (raios e lâmina do C-STS a 100%, cubos e mangas
a ~50%) e o aro como casca fina — e o compara com o arquivo mestre. Foi assim que
apareceu o achado
[A-21](../00_Especificacao_Mestre/02_Auditoria_Tecnica.md#a-21): as quatro rodas
Φ420 pesam **2,55 kg**, não os 1,80 kg orçados. A massa total subiu de 8,72 para
**10,03 kg**, o torque de projeto de 5,40 para **6,44 N·m** e a rigidez do C-STS
de 10,31 para **12,30 N·m/rad**.

Um teste trava isso:
`testes/test_ros_urdf.py::test_massa_das_rodas_bate_com_as_malhas`.

---

## 5. Mundos

Gerados por `ferramentas/gerar_mundo_gazebo.py` — a escada simulada é
**necessariamente** a que dimensiona a roda.

| Mundo | Conteúdo | Para quê |
| :--- | :--- | :--- |
| `percurso_parquetec.sdf` | meio-fio, rampa de 8%, escadaria de 8 degraus, porta de 800 mm, corredor de 900 mm, marcadores da missão | missão de homologação completa |
| `bancada_degrau.sdf` | 4 degraus + meio-fio, passo de 0,5 ms | ensaio ENS-06 instrumentado |
| `escada_molhada.sdf` | mesma escada com μ = 0,55 | a restrição operacional de [A-10](../00_Especificacao_Mestre/02_Auditoria_Tecnica.md#a-10) vira cenário executável |

> O mundo molhado existe para que a restrição "não sobe escada molhada" deixe de
> ser uma frase num documento e passe a ser algo que o piloto **vê acontecer** no
> treinamento.

**Passo de integração.** 1 ms no percurso, 0,5 ms na bancada. O critério é
$\omega\,\Delta t < 0{,}5$ com $\omega = \sqrt{k_p/m_{ns}}$ na variante mais
rígida — verificado por teste automatizado.

---

## 6. Tópicos: a simulação fala a língua do firmware

A ponte `ros_gz` e o registrador foram montados para que os dados de simulação
sejam **diretamente comparáveis** aos de ensaio de campo, sem conversão:

| Tópico | Tipo | Origem no rover real |
| :--- | :--- | :--- |
| `/cmd_vel` | `geometry_msgs/Twist` | comandos do rádio ELRS |
| `/cinematica_4ws/modo` | `std_msgs/String` | chave de modo no transmissor |
| `/imu` | `sensor_msgs/Imu` | BNO055 (com ruído representativo) |
| `/camera_fpv/image_raw` | `sensor_msgs/Image` | câmera FPV 150°, 640×480 |
| `/joint_states` | `sensor_msgs/JointState` | encoders + realimentação dos servos |
| `/contatos` | `ros_gz_interfaces/Contacts` | *(só em simulação)* onde a roda toca |
| `/odom_verdade` | `nav_msgs/Odometry` | *(só em simulação)* referência para medir o erro de odometria |
| `/tracao/eletrico` | `Float64MultiArray` | corrente, tensão, SOC, Wh, temperatura, taxa C |
| `/supervisor/estado` | `std_msgs/String` | máquina de estados de `02_Engenharia/08` |
| `/molas_passivas/energia_csts` | `Float64MultiArray` | energia armazenada nas quatro molas |

O CSV do registrador tem **as mesmas colunas** que o gêmeo digital 3D exporta.

> **Sobre `/contatos`:** é o tópico que permite verificar *onde* a roda toca —
> no nariz, no piso ou na **face do espelho**. O apoio na face do espelho é
> exatamente o modo de falha do achado A-01, e sem instrumentar o contato ele
> apareceria apenas como "o rover não subiu", sem explicar por quê. As pontas dos
> raios são colisões **nomeadas** (`ponta_FL_0`…) justamente para o sensor de
> contato poder referenciá-las.
>
> **Sobre `/odom_verdade`:** não é a odometria do rover. É a referência contra a
> qual medir o **erro** da odometria por encoder, que a complacência do C-STS
> degrada (30° de atraso da roda em relação ao motor sob torque nominal). É o
> ensaio ENS-15, executável em simulação antes de existir hardware.

---

## 7. Como rodar

```bash
cd ros2_ws
rosdep install --from-paths src --ignore-src -r -y
colcon build --symlink-install
source install/setup.bash

# Missão completa, com aro elástico
ros2 launch rover_frugal_bringup missao.launch.py

# Ensaio de escada, sem interface, telemetria em CSV
ros2 launch rover_frugal_bringup ensaio_escada.launch.py arquivo:=/tmp/ens06.csv

# Escada com piso molhado — a restrição de A-10, executável
ros2 launch rover_frugal_gazebo simulacao.launch.py \
    mundo:=escada_molhada.sdf aro_elastico:=false

# Só a geometria, no RViz
ros2 launch rover_frugal_description visualizar.launch.py
```

Pilotagem, em outro terminal:

```bash
ros2 run teleop_twist_keyboard teleop_twist_keyboard
ros2 topic pub --once /cinematica_4ws/modo std_msgs/String "data: crab"
ros2 topic pub --once /supervisor/piso_seco std_msgs/Bool "data: true"
```

---

## 8. Verificação sem ROS instalado

O pacote é validado na integração contínua **sem instalar ROS**: `xacro` e
`yourdfpy` vêm do PyPI, expandem o xacro e carregam o URDF.

```bash
python3 -m pytest testes/test_ros_urdf.py testes/test_ros_controle.py -v
```

| Verificação | O que garante |
| :--- | :--- |
| massa do URDF = massa do arquivo mestre | o robô simulado é o robô projetado |
| inércias positivas-definidas e com desigualdade triangular | o solver não explode por tensor impossível |
| FK das rodas = entre-eixos e bitola de projeto | geometria correta |
| limites de junta = curso do servo, curso da suspensão, batente do C-STS | limites físicos, não arbitrários |
| esferas de colisão sem lacuna e dentro de $r_{max}$ | contato fiel ao raio curvo |
| colisão no ventre na cota do vão livre | encalhe no nariz é detectável |
| escada do mundo = escada do projeto | não se simula outra escada |
| $\omega\,\Delta t < 0{,}5$ | passo de integração resolve o contato |
| cinemática do nó ROS = `simulador_python.kinematics` | **ENS-01 em software** |
| curva do motor do nó ROS = `simulador_python.powertrain` | o motor simulado é o motor dimensionado |
| torque cai com a rotação | a falha silenciosa de "stall a qualquer velocidade" não passa |
| PI de tração tem anti-windup | o rover não "pula" o degrau ao sair da saturação |
| supervisor: 43° de arfagem em escada não dispara proteção | o limiar por modo funciona |
| supervisor: I²t corta e retoma após resfriar | a proteção térmica é integral |

---

## 9. Limitações conhecidas

1. **O colapso local do aro não é simulado** (§4.4). São duas variantes, e a
   transição entre elas fica com o modelo Python.
2. **Deformação do PVC não é modelada.** Os braços são rígidos; a flexão real
   dos tubos muda um pouco a geometria de contato sob carga.
3. **Histerese do elástico** é aproximada por amortecimento viscoso linear.
4. **O modelo elétrico roda como nó, não como `hardware_interface`.** A curva do
   motorredutor, a queda de tensão e o I²t estão implementados e testados, mas
   num nó ROS a 200 Hz. Migrá-los para um `hardware_interface` permitiria usar o
   mesmo binário em simulação e no hardware.
5. **Descida de escada** não foi analisada com o mesmo rigor da subida — vale
   para todos os modelos do projeto.
6. **Custo de contato.** A variante sem aro tem 324 esferas de colisão no total;
   ela é feita para os mundos de ensaio, não para o percurso completo.

---

## 10. Próximos passos

| Passo | Por quê |
| :--- | :--- |
| Migrar o nó `tracao` para um `hardware_interface` | hoje o modelo do motorredutor roda como nó; dentro do `ros2_control` ele serviria simulação e hardware com o mesmo binário |
| Rodar ENS-06 em simulação e comparar com o modelo sagital | fecha o laço de validação previsto em `03_Simulacao/04` §4.3 |
| Aproximação oblíqua da escada | é o caso que só o modelo 3D pode responder (H1 do documento de V&V) |
| `ros2_control` no ESP32 via micro-ROS | permite que o **mesmo** nó de cinemática rode embarcado, cumprindo ENS-01 em hardware |

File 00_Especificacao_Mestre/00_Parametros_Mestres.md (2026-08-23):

# 00. Parâmetros Mestres do Projeto

> **DOCUMENTO GERADO AUTOMATICAMENTE** — não editar à mão.
> Fonte: [`parametros_mestres.yaml`](parametros_mestres.yaml) ·
> Gerador: [`ferramentas/gerar_documentacao.py`](../ferramentas/gerar_documentacao.py) ·
> Regerar: `python3 ferramentas/gerar_documentacao.py`

| | |
| :--- | :--- |
| Revisão | **R2** (2026-08-22) |
| Variante ativa | **v2_sincrona** |
| Variantes disponíveis | `v1_legado`, `v2_sincrona`, `v3_degrau_reduzido` |
| Fonte da revisão | `parametros_mestres.yaml` (2026-08-22) |

Variante ativa (R2). Roda Φ400 mm com 3 raios satisfaz a condição D = 2·r_max·sin(π/N) para o degrau de referência, e o entre-eixos é travado em 2 passos de degrau para sincronizar os eixos na escada.

---

## 1. Por que este arquivo existe

Antes da revisão R2 o mesmo número aparecia com valores diferentes em lugares
diferentes: a roda era Φ240 mm em um documento, Φ300 mm em outro e r = 0,10 m no
cálculo de torque; a massa era 7,5 kg no simulador e 10 kg no dimensionamento
elétrico; a roda tinha 3 raios em cinco documentos e 4 no catálogo de peças. Cada
divergência dessas é um erro de projeto esperando a fase de fabricação para
aparecer.

A regra passa a ser: **nenhum número de engenharia é digitado duas vezes.** Todo
valor vive em `parametros_mestres.yaml` e é consumido por:

```
parametros_mestres.yaml
   │
   ├─ simulador_python/config.py ──── simulador, benchmarks e Relatório de Engenharia
   ├─ prototipo_3d/parametros.js ──── gêmeo digital 3D  (gerar_parametros_js.py)
   └─ 00_Parametros_Mestres.md ────── esta tabela        (gerar_documentacao.py)
```

---

## 2. Resumo executivo da configuração

```
Variante ativa .............. v2_sincrona
Massa total (nominal) ....... 10.03 kg  (98.4 N)
Entre-eixos x bitola ........ 690 x 600 mm
Altura do CG ................ 266 mm
Tombamento long. / lat. ..... 52.3° / 48.4°
Escada de referência ........ E=170 mm, P=300 mm, 2E+P=64.0 cm, passo D=344.8 mm, 29.5°
Roda ........................ N=3 raios, r_max=210 mm (Φ420 mm), r_cubo=70 mm
Alcance nariz-a-nariz ....... 363.7 mm (exigido 344.8 mm) -> SÍNCRONA
C-STS ....................... kt_projeto=12.30 N·m/rad (artigo: 0.55 N·m/rad em outra escala)
Torque de stall por roda .... 12.49 N·m (redução 1:172)
Pack de bateria ............. 4S2P LiFePO4, 6.0 Ah, 77 Wh (61 Wh úteis)
Cinemática (Siegwart) ....... δm=1, δs=2, δM=3 (holonômico: não)
```

---

## 3. Verificações automáticas de coerência

| Verificação | Resultado |
| :--- | :--- |
| Blondel 2E + P na faixa NBR 9050 (0,63–0,65 m) | 0.640 m — ✔ |
| Marcha síncrona: D ≤ 2·r_max·sin(π/N) | 344.8 ≤ 363.7 mm — ✔ |
| Entre-eixos travado em fase (L = k·D) | 0.690 = 2·0.3448 — ✔ |
| Vão livre do ventre > espelho do degrau | 190 > 170 mm — ✔ |
| Pêndulo estável (CG abaixo da fixação) | braço = 91 mm — ✔ |
| δM = δm + δs | 3 = 1 + 2 — ✔ |
| Margem de tombamento na escada ≥ KPI | 22.8° ≥ 10° — ✔ |
| Atrito exigido na escada < disponível (seco) | 0.72 < 0.85 — ✔ |

Essas verificações são executadas como testes em `testes/test_parametros.py`.

---

## 4. Tabela completa de parâmetros

### meta

| Parâmetro | Valor | Unid. |
| :--- | ---: | :--- |
| `projeto` | Rover Frugal 4WD/4WS — UGV de Inovação Frugal para Logística Predial |  |
| `revisao` | R2 |  |
| `data_revisao` | 2026-08-22 |  |
| `variante_ativa` | v2_sincrona |  |
| `descricao_revisao` | R2 consolida a auditoria técnica (00_Especificacao_Mestre/02_Auditoria_Tecnica.md), corrige o dimensionamento da roda pela condição de marcha síncrona de raios, unifica massas, raios e contagem de raios entre documentos e código, e corrige a classificação cinemática de Siegwart (δm=1, δs=2, δM=3).
 |  |
| `variantes_disponiveis` | v1_legado, v2_sincrona, v3_degrau_reduzido |  |
| `descricao_variante` | Variante ativa (R2). Roda Φ400 mm com 3 raios satisfaz a condição D = 2·r_max·sin(π/N) para o degrau de referência, e o entre-eixos é travado em 2 passos de degrau para sincronizar os eixos na escada.
 |  |

### ambiente

| Parâmetro | Valor | Unid. |
| :--- | ---: | :--- |
| `porta_estreita` | 0.8 |  |
| `corredor_estreito` | 0.9 |  |

#### ambiente · escada

| Parâmetro | Valor | Unid. |
| :--- | ---: | :--- |
| `espelho_E` | 0.17 | m |
| `piso_P` | 0.3 | m |
| `largura` | 1.2 |  |
| `num_degraus_lance` | 8 |  |
| `blondel_2E_mais_P` | 0.64 |  |
| `passo_D` | 0.3448 | m |
| `inclinacao_rad` | 0.5155 |  |
| `inclinacao_deg` | 29.54 |  |

#### ambiente · meio_fio

| Parâmetro | Valor | Unid. |
| :--- | ---: | :--- |
| `altura_tipica` | 0.12 |  |
| `altura_maxima` | 0.15 |  |

#### ambiente · piso

| Parâmetro | Valor | Unid. |
| :--- | ---: | :--- |
| `mu_borracha_concreto` | 0.85 |  |
| `mu_borracha_concreto_molhado` | 0.55 |  |
| `mu_borracha_marmore_polido` | 0.4 |  |
| `crr_asfalto` | 0.03 |  |
| `crr_grama` | 0.11 |  |

### veiculo

| Parâmetro | Valor | Unid. |
| :--- | ---: | :--- |
| `entre_eixos_L` | 0.69 | m |
| `bitola_W` | 0.6 | m |
| `fator_fase_escada_k` | 2 |  |
| `altura_cg_chassi` | 0.28 |  |
| `altura_cg_carga` | 0.225 |  |
| `altura_caixa` | 0.25 |  |
| `altura_fixacao_pendular` | 0.357 |  |
| `vao_livre_ventre` | 0.19 |  |
| `folga_ventre_medida` | 0.079 |  |
| `braco_pendular` | 0.09071 |  |
| `amortecimento_pendular` | 4.5 |  |
| `peso_total_N` | 98.36 | N |
| `altura_cg_total` | 0.2663 |  |
| `lf` | 0.345 |  |
| `lr` | 0.345 |  |
| `angulo_tombamento_long_deg` | 52.34 |  |
| `angulo_tombamento_lat_deg` | 48.41 |  |
| `pendulo_estavel` | sim |  |

### massas

| Parâmetro | Valor | Unid. |
| :--- | ---: | :--- |
| `chassi_pvc` | 1.3 |  |
| `rodas_conjunto` | 2.55 |  |
| `tracao_conjunto` | 0.92 |  |
| `estercamento_conjunto` | 0.85 |  |
| `eletronica_potencia` | 0.55 |  |
| `bateria` | 0.76 |  |
| `caixa_organizadora` | 0.6 |  |
| `carga_util_nominal` | 2.5 |  |
| `carga_util_maxima` | 3 |  |
| `massa_seca` | 7.53 |  |
| `massa_total` | 10.03 | kg |
| `massa_total_maxima` | 10.53 |  |

### roda

| Parâmetro | Valor | Unid. |
| :--- | ---: | :--- |
| `num_raios_N` | 3 |  |
| `raio_max` | 0.21 | m |
| `raio_cubo` | 0.07 | m |
| `raio_curvatura_arco` | 0.189 |  |
| `largura_raio` | 0.024 |  |
| `espessura_raiz` | 0.01 |  |
| `espessura_ponta` | 0.007 |  |
| `varredura_rad` | 1.35 |  |
| `expoente_perfil` | 0.85 |  |
| `sentido_curvatura` | 1 |  |
| `material` | PETG |  |
| `densidade_material` | 1270 |  |
| `passo_angular_rad` | 2.094 |  |
| `alcance_nariz_a_nariz` | 0.3637 |  |
| `raio_sincrono_exigido` | 0.1991 |  |
| `marcha_sincrona` | sim |  |
| `folga_sincronismo` | 0.01891 |  |
| `raio_medio_rolamento` | 0.14 |  |

#### roda · pastilha_borracha

| Parâmetro | Valor | Unid. |
| :--- | ---: | :--- |
| `espessura` | 0.008 |  |
| `mu` | 0.85 |  |

### aro_elastico

| Parâmetro | Valor | Unid. |
| :--- | ---: | :--- |
| `obrigatorio` | sim |  |
| `tipo` | câmara de ar de bicicleta 20" (frugal) ou anel TPU 95A impresso |  |
| `rigidez_radial` | 3500 |  |
| `curso_colapso` | 0.025 |  |
| `massa_por_roda` | 0.09 |  |
| `forca_colapso_local` | 90 |  |

### csts

| Parâmetro | Valor | Unid. |
| :--- | ---: | :--- |
| `modulo_young_pla` | 3.500e+09 |  |
| `modulo_young_petg` | 2.100e+09 |  |
| `material` | PETG |  |
| `largura_b` | 0.03 |  |
| `espessura_t` | 0.0103 |  |
| `comprimento_desenrolado_L` | 0.386 |  |
| `raio_interno_espiral` | 0.02 |  |
| `raio_externo_espiral` | 0.062 |  |
| `torque_projeto` | 6.44 | N·m |
| `deflexao_projeto_deg` | 30 |  |
| `kt_projeto` | 12.3 | N·m/rad |
| `kt_empirico` | 0.547 |  |
| `fator_correcao_empirico` | 0.828 |  |
| `amortecimento_ct` | 0.08 |  |
| `deflexao_maxima_deg` | 35 |  |
| `inercia_roda` | 0.0125 |  |
| `modulo_young` | 2.100e+09 |  |
| `kt_teorico` | 14.86 |  |
| `deflexao_maxima_rad` | 0.6109 |  |

### suspensao_elastica

| Parâmetro | Valor | Unid. |
| :--- | ---: | :--- |
| `elasticos_por_perna` | 8 |  |
| `rigidez_por_elastico` | 125 |  |
| `amortecimento_por_roda` | 25 |  |
| `curso_maximo` | 0.09 |  |
| `afundamento_estatico` | 0.022 |  |
| `pre_tensao_relativa` | 0.2 |  |
| `batente_deg` | 25 |  |
| `rigidez_por_roda` | 1000 |  |

### powertrain

| Parâmetro | Valor | Unid. |
| :--- | ---: | :--- |
| `reducao` | 172 |  |
| `eficiencia_reducao` | 0.72 |  |
| `num_motores` | 4 |  |
| `limite_corrente_driver` | 20 |  |
| `torque_stall_saida` | 12.49 |  |
| `rpm_vazio_saida` | 69.77 |  |
| `omega_vazio_saida` | 7.306 |  |

#### powertrain · motor

| Parâmetro | Valor | Unid. |
| :--- | ---: | :--- |
| `tensao_nominal` | 12 |  |
| `kv_rpm_por_volt` | 1000 |  |
| `resistencia_armadura` | 1.1 |  |
| `corrente_vazio` | 0.35 |  |
| `torque_stall_rotor` | 0.0265 |  |
| `inercia_rotor` | 1.200e-06 |  |
| `kt_nm_por_a` | 0.009549 |  |
| `corrente_stall` | 10.91 |  |
| `torque_stall_calc` | 0.1008 |  |

### estercamento

| Parâmetro | Valor | Unid. |
| :--- | ---: | :--- |
| `torque_servo` | 2.45 |  |
| `velocidade_servo` | 5.24 |  |
| `angulo_maximo_deg` | 55 |  |
| `taxa_maxima_deg_s` | 120 |  |
| `tempo_reconfiguracao_modo` | 0.75 |  |

### energia

| Parâmetro | Valor | Unid. |
| :--- | ---: | :--- |
| `quimica` | LiFePO4 |  |
| `celulas_serie` | 4 |  |
| `celulas_paralelo` | 2 |  |
| `capacidade_celula_ah` | 3 |  |
| `tensao_nominal_celula` | 3.2 |  |
| `tensao_cheia_celula` | 3.65 |  |
| `tensao_corte_celula` | 2.8 |  |
| `resistencia_interna_celula` | 0.025 |  |
| `reserva_operacional` | 0.2 |  |
| `consumo_eletronica_w` | 6.5 |  |
| `tensao_nominal_pack` | 12.8 |  |
| `tensao_cheia_pack` | 14.6 |  |
| `tensao_corte_pack` | 11.2 |  |
| `capacidade_ah` | 6 |  |
| `energia_wh` | 76.8 |  |
| `energia_util_wh` | 61.44 |  |
| `resistencia_interna_pack` | 0.05 |  |

### cinematica

| Parâmetro | Valor | Unid. |
| :--- | ---: | :--- |
| `grau_mobilidade_dm` | 1 |  |
| `grau_dirigibilidade_ds` | 2 |  |
| `grau_manobrabilidade_dM` | 3 |  |
| `holonomico` | não |  |
| `velocidade_maxima` | 1.2 |  |
| `velocidade_escada` | 0.25 |  |
| `aceleracao_maxima` | 0.5 |  |
| `grau_manobrabilidade_calc` | 3 |  |

### controle

| Parâmetro | Valor | Unid. |
| :--- | ---: | :--- |
| `frequencia_malha_hz` | 200 |  |
| `frequencia_telemetria_hz` | 20 |  |
| `timeout_failsafe_ms` | 300 |  |
| `pitch_critico_plano_deg` | 35 |  |
| `pitch_critico_escada_deg` | 52 |  |
| `roll_critico_deg` | 30 |  |
| `limite_choque_carga_g` | 2 |  |
| `arfagem_esperada_escada_deg` | 43 |  |

### kpi

| Parâmetro | Valor | Unid. |
| :--- | ---: | :--- |

#### kpi · carga_util_kg

| Parâmetro | Valor | Unid. |
| :--- | ---: | :--- |
| `meta` | 3 |  |
| `minimo` | 2.5 |  |

#### kpi · degrau_transponivel_m

| Parâmetro | Valor | Unid. |
| :--- | ---: | :--- |
| `meta` | 0.17 |  |
| `minimo` | 0.15 |  |

#### kpi · velocidade_plano_ms

| Parâmetro | Valor | Unid. |
| :--- | ---: | :--- |
| `meta` | 1 |  |
| `minimo` | 0.5 |  |

#### kpi · choque_carga_g

| Parâmetro | Valor | Unid. |
| :--- | ---: | :--- |
| `meta` | 1.5 |  |
| `maximo` | 2.5 |  |

#### kpi · autonomia_min

| Parâmetro | Valor | Unid. |
| :--- | ---: | :--- |
| `meta` | 45 |  |
| `minimo` | 30 |  |

#### kpi · alcance_link_m

| Parâmetro | Valor | Unid. |
| :--- | ---: | :--- |
| `meta` | 300 |  |
| `minimo` | 150 |  |

#### kpi · troca_peca_min

| Parâmetro | Valor | Unid. |
| :--- | ---: | :--- |
| `meta` | 10 |  |
| `maximo` | 15 |  |

#### kpi · custo_material_usd

| Parâmetro | Valor | Unid. |
| :--- | ---: | :--- |
| `meta` | 1000 |  |
| `maximo` | 1000 |  |

#### kpi · margem_torque

| Parâmetro | Valor | Unid. |
| :--- | ---: | :--- |
| `meta` | 2 |  |
| `minimo` | 1.5 |  |

#### kpi · margem_tombamento_deg

| Parâmetro | Valor | Unid. |
| :--- | ---: | :--- |
| `meta` | 15 |  |
| `minimo` | 10 |  |

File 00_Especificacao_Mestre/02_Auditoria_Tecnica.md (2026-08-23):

# 02. Auditoria Técnica do Projeto (R1 → R2)
## Achados, evidências e resoluções

> **Propósito.** Este documento registra, com evidência reproduzível, cada
> divergência ou erro encontrado na revisão R1 do projeto e o que foi feito a
> respeito. Ele existe para que ninguém precise redescobrir o mesmo problema
> — e para que a decisão de mudar (ou não mudar) o projeto seja rastreável.
>
> **Como ler.** Cada achado tem: o que estava escrito, por que está errado,
> o comando que reproduz a verificação, e a resolução adotada.
>
> **Severidade.** 🔴 impede a missão · 🟠 compromete requisito · 🟡 inconsistência
> documental · 🔵 melhoria de método.

---

## Sumário dos achados

| # | Achado | Severidade | Situação |
| :--- | :--- | :---: | :--- |
| [A-01](#a-01) | A roda Φ300 mm não transpõe o degrau de referência | 🔴 | Resolvido — Φ420 mm |
| [A-02](#a-02) | Roda de 3 raios é inutilizável em piso plano sem aro | 🔴 | Resolvido — aro elástico é item crítico |
| [A-03](#a-03) | Curso de suspensão de 35 mm satura na escada | 🔴 | Resolvido — 90 mm |
| [A-04](#a-04) | Rigidez do C-STS copiada de outra escala | 🔴 | Resolvido — redimensionada |
| [A-05](#a-05) | Classificação cinemática de Siegwart incorreta (δm+δs≠δM) | 🟠 | Resolvido — δm=1, δs=2 |
| [A-06](#a-06) | Holonomia declarada sem base; custo de troca de modo ignorado | 🟠 | Resolvido — documentado |
| [A-07](#a-07) | Torque calculado com raio de roda errado (0,10 m) | 🟠 | Resolvido — modelo completo |
| [A-08](#a-08) | Limite térmico dos motores nunca avaliado | 🟠 | Resolvido — I²t no firmware |
| [A-09](#a-09) | Limiar anti-tombamento dispara na subida normal | 🟠 | Resolvido — limiar por modo |
| [A-10](#a-10) | Atrito exigido na escada sem margem para piso molhado | 🟠 | Resolvido — restrição operacional |
| [A-11](#a-11) | Benchmark do C-STS produzido por fator de ajuste | 🔵 | Resolvido — física derivada |
| [A-12](#a-12) | Roda de raios era decorativa no protótipo 3D | 🔵 | Resolvido — contato real |
| [A-13](#a-13) | Contagem de raios divergente (3 x 4) | 🟡 | Resolvido — fonte única |
| [A-14](#a-14) | Massa divergente (7,5 kg x 10 kg) | 🟡 | Resolvido — fonte única |
| [A-15](#a-15) | Comprimentos de tubo do roteiro não fecham com a geometria | 🟡 | Resolvido — derivados do CAD |
| [A-16](#a-16) | Todos os links da documentação apontavam para `file:///d:/...` | 🟡 | Resolvido — links relativos |
| [A-17](#a-17) | Protótipo dependia de CDN externo | 🟡 | Resolvido — Three.js versionado |
| [A-18](#a-18) | `prototipo_3d_standalone.html` era cópia manual divergente | 🟡 | Resolvido — passou a ser build |
| [A-19](#a-19) | Economia "de até 75%" contra skid-steer sem base | 🟡 | Resolvido — modelo de Wong |
| [A-20](#a-20) | Ausência de rastreabilidade requisito → verificação | 🔵 | Resolvido — matriz de requisitos |
| [A-21](#a-21) | Massa das rodas subestimada em 41% | 🟠 | Resolvido — reconciliada com as malhas |
| [A-22](#a-22) | ROS 2, Gazebo, URDF e gêmeo digital só existiam como menção | 🟠 | Resolvido — workspace implementado |

---

## A-01 🔴 A roda Φ300 mm não transpõe o degrau de referência

**O que estava escrito.** `02_Engenharia/05` deduzia o raio da roda assim:

> avanço linear por raio Δs = 2πr/3 ≥ P = 300 mm ⟹ r ≥ 143,26 mm,
> adotado r_max = 150 mm (Φ 300 mm).

**Por que está errado.** O critério usado é o de *rolamento em piso plano*: ele
compara o arco percorrido por raio com a **profundidade** do degrau. Mas uma roda
de raios não rola sobre a escada — ela **salta de nariz em nariz**. A distância a
vencer não é o piso *P*, é a diagonal nariz-a-nariz:

$$D = \sqrt{E^2 + P^2} = \sqrt{170^2 + 300^2} = 344{,}8\text{ mm}$$

E o alcance máximo de dois raios consecutivos, ambos tocando pela ponta, é a
corda do polígono regular inscrito:

$$\text{alcance} = 2\,r_{max}\,\sin(\pi/N)$$

**Condição de marcha síncrona (Eq. 1):**

$$\boxed{\;D \;\le\; 2\,r_{max}\sin(\pi/N)
\qquad\Longleftrightarrow\qquad
r_{max}\;\ge\;\frac{D}{2\sin(\pi/N)}\;}$$

Para *N* = 3 e o degrau de referência: **r_max ≥ 199,1 mm**.
A roda de R1 tem alcance de apenas **259,8 mm** contra **344,8 mm** exigidos —
déficit de 85 mm. Ela não alcança o nariz seguinte: cai no canto do degrau e
acaba apoiando na **face vertical do espelho**, onde a reação necessária sai do
cone de atrito e a roda escorrega em vez de subir.

**Evidência.**

```bash
python3 -c "
from simulador_python.geometria_escada import avaliar_robustez
print(avaliar_robustez(3, 0.150, 0.17, 0.30, raio_cubo=0.045).resumo())"
```

```
N=3 r_max=150 mm (Φ300 mm) em degrau 170x300 mm
  marcha síncrona ....... NÃO (margem -85.0 mm)
  robustez de fase ...... 0% das fases de aproximação escalam
```

Comparação das duas rodas

**Resolução.** O diâmetro foi redimensionado por **robustez de fase**: a fase com
que a roda chega ao primeiro degrau não é controlável pelo piloto, então o
projeto precisa escalar a partir de *qualquer* fase, e em *qualquer* escada da
família de Blondel (2E+P = 64 cm, E de 160 a 180 mm).

| Φ [mm] | E16/P32 | E17/P30 | E18/P28 | pior caso |
| ---: | ---: | ---: | ---: | ---: |
| 300 | 0% | 0% | 0% | **0%** |
| 400 | 75% | 83% | 92% | 75% |
| **420** | **100%** | **100%** | **100%** | **100%** ✔ |
| 440 | 100% | 100% | 100% | 75%¹ |
| 460 | 83% | 75% | 83% | 75% |

¹ falha em escadas fora de norma (E16/P28): a roda **sobredimensionada** ultrapassa
o nariz e cai dentro do degrau. O sucesso não é monotônico no raio — existe um
ótimo, e ele é **Φ420 mm**.

Consequências adotadas: entre-eixos travado em fase com a escada
(*L* = 2·D = 690 mm), vão livre do ventre de 190 mm e massa das rodas revista.

---

## A-02 🔴 A roda de 3 raios é inutilizável em piso plano sem aro elástico

**O que estava escrito.** O anel externo de banda de rodagem aparecia como
`CAD-07 — Tire-Tread-Ring (Opcional)`.

**Por que está errado.** Uma roda de *N* raios sem aro é uma *rimless wheel*. A
cota do cubo oscila entre `r_max` (raio apoiado na vertical) e `r_max·cos(π/N)`
(transferência entre raios). Para N = 3 e r_max = 210 mm:

$$\Delta y = r_{max}\left(1-\cos\frac{\pi}{N}\right) = 210\,(1-0{,}5) = \mathbf{105\ mm}$$

**105 mm de queda a cada 120° de rotação, em asfalto liso.** A missão é
majoritariamente piso plano — e o requisito de choque na carga é de 2,0 g.

**Evidência.**

```bash
python3 -m pytest testes/test_geometria_escada.py::test_ripple_em_piso_plano_e_o_da_roda_sem_aro -q
python3 -m pytest testes/test_suspensao.py::test_aro_elastico_e_indispensavel_em_piso_plano -q
```

Dinâmica com a carga a bordo, a 0,9 m/s em piso plano:

| Configuração | Pico na carga |
| :--- | ---: |
| com aro elástico | **0,58 g** ✔ |
| sem aro elástico | **7,69 g** ✘ |

**Resolução.** O aro passa a ser **item crítico, não opcional**, com bloco próprio
no arquivo mestre (`aro_elastico`). Ele fecha a superfície de rolamento no plano
e **colapsa localmente** na quina do degrau, liberando a ponta do raio para
engatar. A rigidez radial (3500 N/m) e a força de colapso local (90 N) são
parâmetros de projeto a **calibrar em bancada** — ver ensaio ENS-04 no protocolo
de testes.

> **Tensão de projeto a registrar.** Rolamento suave em piso plano e marcha
> síncrona em escada puxam para lados opostos: piso plano quer muitos raios
> (N ≥ 14 para ripple < 5 mm), escada quer poucos (N = 3 minimiza o raio). O aro
> elástico é o que permite atender aos dois com N = 3.

---

## A-03 🔴 Curso de suspensão de 35 mm satura na escada

**O que estava escrito.** `MAX_SUSP_TRAVEL = 0.035` (35 mm), sem justificativa.

**Por que está errado.** A marcha síncrona impõe quedas de cubo de até **89 mm**.
A energia a dissipar é

$$U = m\,g\,\Delta h = 8{,}72 \times 9{,}81 \times 0{,}089 = 7{,}6\ \text{J}$$

Com 35 mm de curso a suspensão bate no batente a cada transferência de raio e
transmite o choque direto à carga.

**Evidência.** Varredura curso × rigidez (escada, 0,25 m/s):

| Curso | Pico vertical na carga |
| ---: | ---: |
| 35 mm | 2,09 g ✘ (limite 2,0 g) |
| 60 mm | 1,37 g |
| **90 mm** | **0,81 g** ✔ |
| 110 mm | 0,81 g (sem ganho adicional) |

**Resolução.** Curso de **90 mm** com rigidez de **1000 N/m por roda**
(8 elásticos × 125 N/m), afundamento estático de 22 mm — 24% do curso, boa
prática veicular. Isso **muda o projeto mecânico do braço**: a manga de eixo
precisa de 90 mm de deslocamento vertical guiado, não 35 mm.

---

## A-04 🔴 A rigidez do C-STS foi copiada de outra escala

**O que estava escrito.** `KT_EMPIRICAL = 0.547` N·m/rad, valor medido por
Jeong & Kim (2025).

**Por que está errado.** Aquele valor foi medido no robô **do artigo**. Neste
rover o torque de acionamento de pico é de 5,40 N·m, o que daria

$$\Delta\theta = \frac{5{,}40}{0{,}547} = 9{,}87\ \text{rad} = 566^\circ$$

A mola enrolaria completamente e bateria no batente na primeira transferência de
raio. Transportar um resultado experimental entre escalas exige **semelhança
dimensional**, não cópia do número.

**Resolução.** A rigidez passa a ser **derivada do requisito**: torque de projeto
e deflexão admissível definem `kt = T/Δθ`; a geometria da espiral é resolvida da
rigidez, com verificação de tensão de flexão e de encaixe no cubo.

```
C-STS em PETG: b=30,0 mm, t=9,71 mm, L=386 mm, 1,5 voltas (r 20→62 mm)
  kt teórico / efetivo ..... 12,46 / 10,31 N·m/rad
  torque / deflexão projeto  5,40 N·m @ 30,0°
  tensão de flexão ......... 11,4 MPa (FS = 4,4)
```

O fator 0,828 medido por Jeong & Kim (razão entre rigidez experimental e teórica,
que reflete a aderência parcial entre filetes na impressão FDM) **continua sendo
usado** — é ele, e não o valor absoluto, o resultado transferível do artigo.

> **Efeito colateral relevante para a eletrônica.** Sob torque nominal a roda
> atrasa 30° em relação ao eixo do motor. Encoders montados no motor **não**
> medem a posição da roda: a odometria precisa de encoder no lado da roda ou de
> compensação explícita da complacência. Ver `02_Engenharia/08`.

---

## A-05 🟠 Classificação cinemática de Siegwart incorreta

**O que estava escrito.** Em `README`, `02_Engenharia/03` e `01_Planejamento/01`:

> δm = 2, δs = 4, δM = δm + δs ≥ 3

**Por que está errado.** 2 + 4 = 6, não 3. Além disso, Siegwart demonstra que
δs ≤ 2: com mais de duas rodas direcionais as demais são **redundantes** —
os ângulos não são livres, precisam convergir no mesmo ICR.

**Evidência.** O posto da matriz de restrições de deslizamento é calculado
numericamente:

```bash
python3 -c "
from simulador_python.kinematics import classificar_siegwart
print(classificar_siegwart(coordenado=True))
print(classificar_siegwart(coordenado=False))"
```

| Configuração das rodas | posto(C1s) | δm | δs | δM |
| :--- | ---: | ---: | ---: | ---: |
| coordenada (ICR comum) | 2 | **1** | **2** | **3** |
| descoordenada | 3 | 0 | 2 | — |

**Resolução.** O rover é da categoria **"Two-Steer"** da Tabela 3.1 de Siegwart:
δm = 1, δs = 2, δM = 3. O caso descoordenado não é curiosidade acadêmica: δm = 0
significa que **o veículo trava**. As quatro direções formam um sistema
sobre-restrito e qualquer erro de calibração vira arrasto lateral:

| Erro em UM servo | Arrasto lateral a 1 m/s |
| ---: | ---: |
| 0,5° | 7,8 mm/s |
| 1,0° | 15,5 mm/s |
| 2,0° | 31,1 mm/s |
| 5,0° | 77,6 mm/s |

Daí sai um requisito de montagem que não existia: **calibração dos servos 4WS
com erro ≤ 1,0°**, verificável em bancada.

---

## A-06 🟠 Holonomia declarada sem base, custo de troca de modo ignorado

**O que estava escrito.**

> O veículo é **holonômico no espaço de velocidades instantâneas**.

**Por que está errado.** Holonomia instantânea exige δm = 3 (rodas suecas ou
esféricas). Com rodas padrão direcionais δm = 1: o rover alcança qualquer
movimento no plano, mas **precisa parar e reorientar as rodas** antes de mudar a
direção instantânea.

**Resolução.** O custo de reconfiguração passa a ser um parâmetro do projeto e
entra no cronograma da missão:

| Transição | Tempo |
| :--- | ---: |
| ackermann → caranguejo | 0,56 s |
| ackermann → giro no eixo | 0,51 s |
| ackermann → escada | 0,10 s |

Além disso, o giro no próprio eixo exige β = ±49° (= atan(L/W)), acima dos ±45°
originalmente especificados. O curso de esterçamento foi elevado para **±55°**.

---

## A-07 🟠 Torque de tração calculado com o raio errado

**O que estava escrito.** `02_Engenharia/04` calculava
`T_total = F_total · r` com **r = 0,10 m**, enquanto o resto do projeto usava
0,15 m. O resultado (1,63 N·m por motor) subestima em 50% já pelo raio, e ignora
completamente o torque geométrico de içamento sobre o nariz do degrau.

**Resolução.** Substituído por modelo completo em `simulador_python/powertrain.py`:
curva torque-velocidade real do motor CC, redutor com rendimento, e o **torque de
içamento medido na marcha** (braço horizontal do contato × carga normal).

| Grandeza | R1 | R2 |
| :--- | ---: | ---: |
| Raio adotado | 0,10 m (inconsistente) | 0,210 m |
| Massa | 10 kg (inconsistente) | 8,72 kg |
| Torque de pico exigido | não avaliado | **5,40 N·m** |
| Redução | 1:50 a 1:70 | **1:172** |
| Torque de stall na saída | 3,5 N·m (catálogo) | **12,49 N·m** |
| Margem na escada | não avaliada | **1,67** ✔ (KPI ≥ 1,50) |

A hipótese de carga também foi corrigida: **na subida a transferência é para
trás**, portanto quem faz o esforço de içamento são as rodas **traseiras**
(25,4 N cada), não as dianteiras.

---

## A-08 🟠 O limite térmico dos motores nunca foi avaliado

**Por que importa.** No regime de escada o motor opera a **~11% de rendimento**:
quase toda a potência elétrica vira calor no enrolamento.

| Corrente por motor | Regime térmico | Tempo até 115 °C |
| ---: | ---: | ---: |
| 3,02 A | 115 °C | ∞ (contínua admissível) |
| 5,0 A | 255 °C | 108 s |
| 6,9 A | 457 °C | 50 s |
| 9,2 A | 781 °C | **27 s** |

Um lance de 8 degraus a 0,25 m/s leva ~11 s. **Dois lances consecutivos sem pausa
consomem quase toda a margem térmica.**

**Resolução.** O limite de missão em escada é **térmico, não energético** (a
bateria gasta apenas 15% da energia útil na missão inteira). Requisito novo para
o firmware: **proteção I²t com pausa de resfriamento obrigatória entre lances**
(`02_Engenharia/08`).

---

## A-09 🟠 O limiar anti-tombamento dispara na subida normal

**O que estava escrito.**

> Se o ângulo de arfagem ultrapassar o limiar crítico de 40°, o firmware
> desacelera os motores automaticamente.

**Por que está errado.** A escada de referência tem 29,5° de inclinação, e a
oscilação da marcha de 3 raios soma mais ±14°: a arfagem em **operação normal**
chega a **43°**. O limiar de 40° abortaria toda subida no meio.

**Resolução.** Limiar **dependente de modo**, com o tombamento estático (52,6°)
como referência:

| Modo | Limiar de arfagem |
| :--- | ---: |
| piso / rampa | 35° |
| escada | 52° |

---

## A-10 🟠 Atrito exigido na escada não tem margem para piso molhado

**Evidência.** O coeficiente mínimo para subir a 29,5° com resistência de
rolamento de degrau é **μ ≥ 0,72**.

| Superfície | μ disponível | Sobe? |
| :--- | ---: | :---: |
| Concreto seco | 0,85 | ✔ (margem 1,18) |
| Concreto molhado | 0,55 | ✘ |
| Mármore polido | 0,40 | ✘ |

**Resolução.** Restrição operacional explícita: **proibida a subida de escadas com
piso molhado ou polido**, com bloqueio do modo escada no firmware até confirmação
do piloto. Entra no protocolo de missão e na matriz de riscos.

---

## A-11 🔵 O benchmark do C-STS era produzido por fator de ajuste

**O que estava escrito** (`spoke_contact_physics.py`, R1):

```python
if self.phase_name == 'DCS':
    # Desaceleração amortecida em > 50%
    self.deceleration_spike = abs((self.prev_linear_v - cur_v) / dt) * 0.35
else:
    self.deceleration_spike = abs((self.prev_linear_v - cur_v) / dt)
```

**Por que é um problema.** A "redução de 65% do choque com C-STS" não era uma
previsão do modelo: era o próprio fator `0.35` sendo reimpresso na saída. O
gráfico comparativo provava apenas que `0.35 < 1.00`.

**Resolução.** A cadeia causal foi fechada de ponta a ponta, sem nenhum fator
livre:

```
geometria da roda + perfil do degrau
   → SimuladorMarcha devolve a trajetória REAL do cubo (eventos de contato)
   → a queda de cubo medida vira a excitação de base do modelo dinâmico
   → aro, elásticos e C-STS filtram a excitação com suas rigidezes de projeto
   → o pêndulo da caixa filtra o que chega ao notebook
   → a aceleração da carga é INTEGRADA
```

Ligar ou desligar um estágio muda apenas a rigidez correspondente; o ganho
aparece — ou não — por conta própria. O resultado, agora derivado:

| Caminho | Pico na carga |
| :--- | ---: |
| ponta rígida, sem suspensão | 20,2 g |
| só C-STS (estágio 1) | 1,4 g |
| C-STS + elásticos (estágios 1+2) | **1,2 g** |

---

## A-12 🔵 A roda de raios curvos era decorativa no protótipo 3D

**O que estava escrito** (`app.js`, R1):

```javascript
const terrainY = getTerrainHeight(wx, wz);
const targetY = terrainY + 0.15;                      // raio FIXO
roverState.wheelHeights[i] = THREE.MathUtils.damp(roverState.wheelHeights[i], targetY, 10, dt);
```

**Por que é um problema.** A roda era tratada como **disco de raio constante**.
Toda a mecânica que o projeto defende — raios curvos, transferência CCS/DCS,
C-STS, aro elástico — era animação sem efeito. O simulador não conseguiria
mostrar a falha de A-01 nem o ganho de A-02.

**Resolução.** `prototipo_3d/fisica.js` implementa a mesma cadeia do modelo
Python: assentamento real dos raios contra o terreno roda a roda, aro elástico
como piso de contato, quatro massas não suspensas, corpo com arfagem e rolagem,
C-STS integrada, motor com curva real, bateria e térmica. O protótipo agora
**reproduz** o achado A-01 quando se troca para a roda Φ300 pelo botão de
comparação.

---

## A-13 🟡 Contagem de raios divergente

`README`, `02_Engenharia/02`, `02_Engenharia/05` e o simulador diziam **3 raios**;
`03_Simulacao/01` (catálogo CAD, peça `CAD-03`) dizia **4 raios curvos de perfil
espiral logarítmica**. O perfil também divergia: "espiral logarítmica" em um
documento, "arco circular" em outro.

**Resolução.** `roda.num_raios_N = 3` no arquivo mestre, perfil definido por
`varredura_rad` e `expoente_perfil` — a mesma parametrização usada pelo simulador
Python e pelo modelo 3D. N = 3 é justificado em A-01: minimiza o raio exigido.

---

## A-14 🟡 Massa divergente

`simulador_python/config.py` usava 7,5 kg; `02_Engenharia/04` dimensionava a
tração com 10 kg; `01_Planejamento/04` falava em carga útil de 3,0 kg sem
declarar a massa seca.

**Resolução.** Massa passou a ser **soma de subconjuntos declarados**, verificada
por teste (`test_massa_total_e_soma_das_partes`): 6,22 kg secos + 2,50 kg de carga
= **8,72 kg**.

---

## A-15 🟡 Comprimentos de tubo do roteiro não fecham com a geometria

`05_Execucao/01` mandava cortar hastes de 350 mm e 400 mm. Com as posições de
junta do modelo 3D de R1, os tubos necessários eram de 430 mm e 420 mm — e com a
geometria de R2 mudam de novo.

**Resolução.** Os comprimentos de corte deixam de ser digitados no roteiro e
passam a ser **derivados da geometria** (ver `05_Execucao/01`, tabela de corte
gerada a partir do arquivo mestre).

---

## A-16 🟡 Links apontando para o disco local do autor

Todos os links de todos os documentos usavam
`file:///d:/Downloads/Rascunho%20Rover/...`. No GitHub, no computador de qualquer
outra pessoa e na apresentação ao Parquetec, **nenhum deles funciona**.

**Resolução.** Todos convertidos para caminhos relativos.

---

## A-17 🟡 O protótipo dependia de CDN externo

O `index.html` importava Three.js de `unpkg.com`. Sem internet — ou atrás de
proxy corporativo, que é exatamente o caso de um parque tecnológico — o
protótipo abre em tela preta.

**Resolução.** Three.js r160 versionado em `prototipo_3d/vendor/three/`
(licença MIT incluída). O protótipo funciona **offline**.

---

## A-18 🟡 O standalone era uma cópia manual divergente

Existiam duas implementações do protótipo: `prototipo_3d/` (modular) e
`prototipo_3d_standalone.html` (cópia). Elas já haviam divergido em R1.

**Resolução.** O standalone passou a ser **artefato de build**
(`ferramentas/gerar_standalone.py`), com aviso no cabeçalho. Fonte é só uma.

---

## A-19 🟡 Comparação com skid-steer sem base

R1 afirmava economia "de até 75%" e implementava:

```python
p_skid = p_roll_4ws + (lateral_friction_force * linear_speed * 1.8)   # 1.8 = ?
```

**Resolução.** Substituído pelo momento resistente de derrapagem de Wong
(cap. 6), `M_r = μ_t·W·L/4`, com a potência de manobra `M_r·ω`. A 0,8 m/s em
curva de 1,2 m: 2,1 W (4WS) contra 10,5 W (skid-steer) — **80% de economia**,
agora com fórmula rastreável.

---

## A-20 🔵 Não havia rastreabilidade requisito → verificação

R1 tinha KPIs numa tabela e ensaios em outra, sem vínculo. Não era possível
responder "qual ensaio prova o requisito de choque na carga?".

**Resolução.** [`01_Requisitos_e_Rastreabilidade.md`](01_Requisitos_e_Rastreabilidade.md)
com identificadores REQ-###, método de verificação (análise, simulação, ensaio ou
demonstração), artefato de evidência e situação atual de cada requisito.

---

## A-21 🟠 Massa das rodas subestimada em 41%

**Como apareceu.** Ao gerar as malhas STL para o pacote ROS 2 a partir do mesmo
perfil paramétrico usado pela física, o volume de material das peças ficou
disponível — e pôde ser comparado com o orçamento de massa declarado.

**O que estava escrito.** `massas.rodas_conjunto: 1.80` kg, um valor estimado
antes de a geometria existir.

**Medido.** Considerando preenchimento real de impressão (raios e lâmina do C-STS
a 100%, cubos e mangas a ~50%) e o aro como casca fina, cada roda completa pesa:

| Peça | Volume sólido | Material efetivo | Massa |
| :--- | ---: | ---: | ---: |
| Roda (raios + cubo + nervuras + pastilhas) | 328 cm³ | 236 cm³ PETG | 300 g |
| Espiral C-STS | 204 cm³ | 163 cm³ PETG | 207 g |
| Aro elástico (casca de 1,5 mm) | 310 cm³ | 108 cm³ TPU | 130 g |
| **Total por roda** | | | **637 g** |

**4 × 637 g = 2,55 kg**, contra 1,80 kg orçados — **+41%**.

**Propagação.** Corrigidas também as massas de tração (motorredutores 1:172 são
mais pesados), esterçamento (mangas impressas) e bateria (8 células 26650):

| | R2 inicial | R2 corrigido |
| :--- | ---: | ---: |
| Massa seca | 6,22 kg | **7,53 kg** |
| Massa total (com carga) | 8,72 kg | **10,03 kg** |
| Carga por roda traseira na escada | 25,4 N | **30,8 N** |
| Torque de projeto | 5,40 N·m | **6,44 N·m** |
| Rigidez do C-STS | 10,31 N·m/rad | **12,30 N·m/rad** |
| Espessura da lâmina | 9,71 mm | **10,30 mm** |

**Verificações refeitas — todas continuam atendidas:**

| Requisito | Antes | Depois | Limite |
| :--- | ---: | ---: | ---: |
| Robustez de fase na família de Blondel | 100% | **100%** | 100% |
| Margem de torque na escada | 1,92 | **1,61** | ≥ 1,50 ✔ |
| Energia da missão | 15% | **15%** | ≤ 80% ✔ |
| Autonomia em ciclo misto | 64 min | **60 min** | ≥ 30 min ✔ |
| Tombamento longitudinal | 52,6° | **52,3°** | ≥ 39,5° ✔ |
| Curso de suspensão exigido pela energia de queda | 62 mm | **66 mm** | 90 mm ✔ |

**Resolução.** A massa deixou de ser declarada às cegas: um teste
(`test_massa_das_rodas_bate_com_as_malhas`) reprova o arquivo mestre se ele
divergir mais de 20% do volume das malhas geradas.

> **Lição de método.** A massa só ficou verificável quando existiu geometria. É um
> argumento a favor de gerar CAD cedo — não pela peça, mas pelos números que ela
> revela.

---

## A-22 🟠 ROS 2, Gazebo, URDF e gêmeo digital eram só menções

**O que estava escrito.** `03_Simulacao/02` prometia "modelagem multicorpo
(URDF/SDF)" com "motor de física Webots/ODE"; `03_Simulacao/03` prometia um
gêmeo digital do Parquetec com cockpit de pilotagem; `03_Simulacao/01` previa
"exportação STL/STEP/URDF".

**O que existia.** Nada disso. Nenhum arquivo URDF, nenhum mundo, nenhum pacote
ROS, nenhuma malha. Além disso a documentação oscilava entre **Webots** e
**Gazebo** sem decidir — duas cadeias de ferramentas incompatíveis mencionadas
como se fossem intercambiáveis.

**Resolução.** Workspace ROS 2 completo em [`ros2_ws/`](../ros2_ws/), com quatro
pacotes, e a ferramenta decidida: **ROS 2 Jazzy + Gazebo Harmonic** (justificativa
em [`03_Simulacao/05`](../03_Simulacao_e_Prototipacao_Digital/05_ROS2_e_Gazebo.md) §1).

O URDF é **escrito à mão mas sem nenhum número**: carrega
`config/parametros.yaml`, gerado do arquivo mestre. Malhas e mundos idem.

Três decisões de modelagem que a implementação exigiu e que valem registro:

1. **O casco convexo de uma roda de raios é um disco.** Usar a malha como colisão
   faria o motor de física apagar silenciosamente a geometria de raios — e a
   simulação escalaria qualquer escada, inclusive as que o achado A-01 mostra
   serem impossíveis. A colisão é uma cadeia de 81 esferas por roda, com
   espaçamento adaptativo que garante sobreposição.
2. **O aro elástico não colapsa em corpo rígido.** São duas variantes do modelo,
   e a transição entre elas fica com o modelo Python. Declarado como limitação.
3. **Molas passivas num nó ROS, não no SDF.** `<spring_stiffness>` depende do
   motor de física; a lei de mola num nó é portátil e usa as mesmas constantes do
   dimensionamento. Isso trouxe um requisito explícito: a malha precisa rodar a
   **1000 Hz**, não aos 100 Hz habituais de um nó ROS.

**Verificação sem ROS instalado.** 61 testes expandem o xacro com `xacro` do
PyPI, carregam o URDF com `yourdfpy` e conferem massa, inércias, cinemática
direta, limites de junta, geometria de colisão, a escada do mundo e o passo de
integração. A cinemática do nó ROS é comparada com a do simulador a cada
execução: divergência de **8,9 × 10⁻¹⁶ rad** (o ensaio ENS-01 admite 0,1°).

---

## Como reproduzir toda a auditoria

```bash
pip install -r requirements.txt

python3 -m simulador_python.main --parametros   # configuração resolvida
python3 -m simulador_python.main --marcha       # marcha na escada de referência
python3 -m simulador_python.main --sintese      # varredura do espaço de projeto
python3 -m simulador_python.main --relatorio    # relatório completo + figuras
python3 -m pytest testes/ -q                    # 73 verificações automatizadas
```

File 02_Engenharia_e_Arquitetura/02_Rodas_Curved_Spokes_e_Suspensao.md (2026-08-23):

# 02. Rodas em Raios Curvos (*Curved Spokes*) e Suspensão Complacente Torsional (C-STS)
## Fundamentação Matemática Rigorosa baseada em Jeong & Kim (2025), Terramecânica (Wong, 2022) e Mecanismos (Sclater, 2001)

> [!IMPORTANT]
> **Revisão R2 — parcialmente superado**
> A teoria CCS/DCS e o conceito do C-STS continuam válidos, mas o **dimensionamento** deste documento foi refeito: a roda passou de Φ300 mm para **Φ420 mm**, a rigidez do C-STS de 0,547 para **12,30 N·m/rad** e o curso da suspensão de 35 para **90 mm**. Ver [`06_Sintese_da_Roda_e_Geometria_de_Escalada.md`](06_Sintese_da_Roda_e_Geometria_de_Escalada.md).
>
> Parâmetros vigentes: [`00_Especificacao_Mestre/00_Parametros_Mestres.md`](../00_Especificacao_Mestre/00_Parametros_Mestres.md) ·
> Achados: [`02_Auditoria_Tecnica.md`](../00_Especificacao_Mestre/02_Auditoria_Tecnica.md)

---

---

## 1. Definição Geométrica Exata da Roda com 3 Raios Curvos (Jeong & Kim, 2025)

Conforme a caracterização matemática de **Jeong & Kim (2025)** (*Experimental Investigation of a Passive Compliant Torsional Suspension for Curved-Spoke Wheel Stair Climbing, Appl. Sci. 2025, 15, 5985*), a roda é composta por **três raios curvos ($N = 3$)** defasados angularmente em $120^\circ$ ($\Delta\theta = 2\pi/3$):

```
       [Geometria da Roda de 3 Raios Curvos - Jeong & Kim, 2025]
                     .---.
                   /       \
                  |  (C-STS) |----- Eixo Motriz (Motorredutor 12V 4WD)
                 / \       / \
                /   '--.--'   \
               /       |       \
        Raio 1        Raio 2    Raio 3  <-- Arcos de Curvatura com Raio r0
              \        |        /
               '--.    |    .--'
                   \   |   /
             _______'--+--'________
            |  Degrau de Escada ($S \times H = 300\text{ mm} \times 160\text{ mm}$)
```

### 1.1. Equações Cinemáticas de Contato e Fases do Movimento
Durante a escalada de um degrau com largura de piso $S$ e espelho $H$, o raio de curvatura instantâneo $r(t)$ (distância entre o Centro de Rotação - CoR e o ponto de contato com o solo) evolui em duas fases distintas:

1. **Estado de Contato Contínuo (*Continuous Contact State - CCS*)**:
   * O raio de contato cresce monotonicamente de $r_{min}$ (cubo da roda) até $r_{max}$ (ponta do raio):
     $$r(t) \in [r_{min}, r_{max}]$$
   * Sob velocidade angular constante $\omega$, a velocidade linear do CoR cresce continuamente até atingir o pico máximo imediatamente antes da transição:
     $$v_{max, i} = \omega \cdot r_{max}$$

2. **Estado de Contato Descontínuo (*Discontinuous Contact State - DCS*)**:
   * No instante em que o contato salta para o degrau superior, o raio efetivo despenca bruscamente de $r_{max}$ para $r_{min}$.
   * A velocidade linear cai instantaneamente para o valor mínimo:
     $$v_{min, i+1} = \omega \cdot r_{min}$$
   * **Queda de Velocidade Teórica ($\Delta v_i$)**:
     $$\Delta v_i = v_{max, i} - v_{min, i+1} = \omega \cdot (r_{max} - r_{min})$$

---

## 2. A Métrica de Instabilidade Dinâmica e a Solução C-STS

### 2.1. Desaceleração de Impacto na Carga Útil
Devido à inércia do rover e da carga (notebook), a velocidade linear não pode cair instantaneamente a zero. Ocorre uma desaceleração finita e violenta no intervalo $\Delta t_i$ do DCS:

$$a_i = \frac{\Delta v_i}{\Delta t_i} = \frac{v_{max, i-1} - v_{min, i}}{\Delta t_i}$$

Essa desaceleração brusca ($a_i$) gera momentos de tombamento, derrapagem (*wheel slip*) e vibrações prejudiciais à eletrônica.

```mermaid
graph TD
    A[Giro da Roda de 3 Raios Curvos] --> B[Fase CCS: r cresce de r_min a r_max]
    B --> C[Transição DCS: Salto Instantâneo de r_max para r_min]
    C --> D[Queda Brusca Δv_i = ω(r_max - r_min)]
    D --> E[Pico Severo de Desaceleração a_i e Torque de Stall]
    
    subgraph Sistema de Supressão Híbrido: C-STS + Elásticos
        E -.->|Absorvido pelo Cubo| CSTS["<b>Módulo C-STS no Cubo (Jeong & Kim, 2025)</b><br>• Mola Espiral Plana em PLA/PETG<br>• Rigidez Torsional kt = E·b·t³ / (12·L)<br>• Armazena energia em CCS e ejeta em DCS"]
        E -.->|Absorvido pelo Braço| ELAST["<b>Suspensão por Elásticos (Sclater & Chironis)</b><br>• Amortecimento Histerético Natural<br>• Filtragem de Ondulações Verticais"]
        CSTS & ELAST --> F[Redução > 40% na Desaceleração + Ganho de Velocidade Média]
    end
```

---

## 3. Dimensionamento do Mecanismo C-STS (Mola Espiral Plana)

Conforme a formulação de vigas espirais de *Jeong & Kim (2025, Seção 3.3)*, a rigidez torsional teórica da mola espiral plana ($k_t$) é dada por:

$$k_t = \frac{E \cdot b \cdot t^3}{12 \cdot L}$$

Onde:
* $E$: Módulo de elasticidade do material ($E_{PLA} \approx 3,5 \times 10^9 \text{ N/m}^2$, $E_{PETG} \approx 2,1 \times 10^9 \text{ N/m}^2$).
* $b$: Largura axial da espiral.
* $t$: Espessura da lâmina espiral.
* $L$: Comprimento desenrolado da espiral.

> **⚠️ Atenção à escala.** A tabela abaixo reproduz os valores **do artigo**, medidos
> no robô de bancada de Jeong & Kim. Aplicá-los diretamente a este rover seria um
> erro grosseiro: com $r_{max} = 210$ mm e torque de pico de 6,44 N·m, uma mola de
> 0,547 N·m/rad sofreria **674° de deflexão** — enrolaria por completo já no
> primeiro degrau. O que se transporta do artigo é o **método** e o **fator de
> correção 0,828** entre rigidez teórica e experimental (perda de rigidez do FDM),
> não o valor absoluto. A espiral deste projeto (b = 30 mm, t = 10,30 mm,
> L = 386 mm, $k_t$ = 12,30 N·m/rad) é dimensionada em
> [`06 §5`](06_Sintese_da_Roda_e_Geometria_de_Escalada.md).

| Variante do C-STS | Espessura ($t$) | Rigidez Teórica ($k_t$) | Rigidez Experimental Medida | Comportamento em Teste de Escada |
| :--- | :---: | :---: | :---: | :--- |
| **Baixa Rigidez (*Soft*)** | $4,0\text{ mm}$ | $0,246\text{ N}\cdot\text{m/rad}$ | $0,206\text{ N}\cdot\text{m/rad}$ | Máxima absorção de choque, maior deflexão angular. |
| **Média Rigidez (*Baseline*)** | $5,0\text{ mm}$ | $0,661\text{ N}\cdot\text{m/rad}$ | $0,547\text{ N}\cdot\text{m/rad}$ | Configuração ótima **na escala do artigo**. |
| **Alta Rigidez (*Stiff*)** | $6,0\text{ mm}$ | $1,157\text{ N}\cdot\text{m/rad}$ | $0,909\text{ N}\cdot\text{m/rad}$ | Menor deflexão, resposta rígida em alta velocidade. |

---

## 4. Sinergia de Dois Estágios: C-STS no Cubo + Elásticos na Manga

Para aliar a precisão da pesquisa de Jeong & Kim (2025) à filosofia de custo mínimo do projeto frugal, a suspensão opera em **dois estágios complementares**:

```
 [Eixo do Motorredutor 4WD]
             |
     [Módulo C-STS Torsional]  <-- 1º Estágio: Absorve a descontinuidade DCS da roda
             |
     [Roda com 3 Raios Curvos]
             |
    [Manga 4WS com Elásticos] <-- 2º Estágio: Absorve choques verticais do relevo (PVC/Chassi)
```

1. **Estágio 1 (Torsional no Cubo - C-STS)**: Permite que a roda gire brevemente em sentido reverso em relação ao eixo do motor no momento do choque, armazenando energia elástica e a liberando para "catapultar" a ponta do raio sobre o degrau seguinte.
2. **Estágio 2 (Linear na Haste - Elásticos de Escritório)**: Permite o deslocamento vertical suave ($\Delta z$) de toda a manga de eixo, isolando a caixa organizadora pendular de vibrações de alta frequência.

---

## 5. Especificações de Fabricação em Impressão 3D

* **Geometria dos Raios (R2)**: 3 raios em espiral com espessura de $10\text{ mm}$
  na raiz, afinando para $7\text{ mm}$ na ponta, largura axial de $24\text{ mm}$,
  com raio máximo $r_{max} = 210\text{ mm}$ (diâmetro total $420\text{ mm}$).
  *(A versão anterior deste documento dizia $r_{max} = 120$ mm enquanto o resto do
  projeto usava 150 mm — nenhum dos dois transpõe o degrau de referência. O
  dimensionamento correto está em [`06`](06_Sintese_da_Roda_e_Geometria_de_Escalada.md).)*
* **Aro Elástico (item crítico)**: anel externo de câmara de ar de bicicleta 20"
  ou TPU 95A impresso, rigidez radial de $3500\text{ N/m}$. Sem ele o cubo oscila
  $r_{max}(1-\cos(\pi/N)) = 105\text{ mm}$ em piso plano.
* **Ponta de Contato (*Tread Grip*)**: Pastilha de borracha vulcanizada de alta fricção ($\mu > 0,85$) fixada na extremidade de cada raio curvo para garantir engate antiderrapante em quinas de concreto e mármore.
* **Preenchimento de Impressão 3D**: $100\%$ de preenchimento (*solid infill*) nos raios e no anel interno do C-STS para evitar falhas por fadiga de cisalhamento.

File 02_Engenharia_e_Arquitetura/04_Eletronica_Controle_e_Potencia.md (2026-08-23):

# 04. Eletrônica, Arquitetura de Controle e Sistema de Potência
## Dimensionamento Mecatrônico (Sclater & Chironis, 2001), Odometria e Fusão Sensorial (Siegwart & Nourbakhsh, 2004)

> [!IMPORTANT]
> **Revisão R2 — parcialmente superado**
> A arquitetura embarcada continua válida. O **dimensionamento de tração** (§2) usava r = 0,10 m e massa de 10 kg — ambos inconsistentes com o resto do projeto — e foi substituído por [`07_Orcamento_de_Tracao_Energia_e_Termica.md`](07_Orcamento_de_Tracao_Energia_e_Termica.md). O limiar anti-tombamento de 40° (§3) foi substituído por limiar dependente de modo. A arquitetura de software está em [`08_Arquitetura_de_Firmware_e_Seguranca_Funcional.md`](08_Arquitetura_de_Firmware_e_Seguranca_Funcional.md).
>
> Parâmetros vigentes: [`00_Especificacao_Mestre/00_Parametros_Mestres.md`](../00_Especificacao_Mestre/00_Parametros_Mestres.md) ·
> Achados: [`02_Auditoria_Tecnica.md`](../00_Especificacao_Mestre/02_Auditoria_Tecnica.md)

---

---

## 1. Arquitetura Geral do Sistema Embarcado

A eletrônica do rover combina baixo custo, operação em tempo real estrito (*hard real-time*) e alta confiabilidade de potência para acionamento simultâneo de **8 atuadores mecatrônicos** (4 de tração 4WD + 4 de esterçamento 4WS):

```mermaid
graph TD
    subgraph Barramento de Potência (11.1V ~ 14.8V)
        BAT[Bateria LiPo 3S / LiFePO4 4S] --> FUSE[Fusível 30A + Chave E-Stop]
        FUSE --> BUCK_LOGIC[Conversor Buck 5V 5A - Lógica]
        FUSE --> BUCK_SERVO[Conversor Buck 6V/7.4V 10A - Servos 4WS]
        FUSE --> MOT_DRV[2x Pontes H Duplas BTS7960 43A]
    end

    subgraph Controle e Sensores (Tempo Real)
        BUCK_LOGIC --> MCU[Microcontrolador ESP32-S3 Dual-Core]
        MCU --> IMU[Sensor IMU BNO055 / MPU6050 - Pitch/Roll/Yaw]
        MCU --> ENC[Leitura de Encoders em Quadratura 4WD]
        MCU --> RX[Receptor ExpressLRS 915MHz / 2.4GHz]
    end

    subgraph Atuadores e Visão
        BUCK_SERVO --> SERVOS[4x Servos Digitais 25 kgf·cm 4WS]
        MOT_DRV --> MOTORS[4x Motorredutores DC 12V 4WD]
        FUSE --> FPV[Câmera FPV 1200TVL + VTX 5.8GHz 600mW]
        MCU -.->|PWM 4WS| SERVOS
        MCU -.->|PWM + Dir| MOT_DRV
    end
```

---

## 2. Dimensionamento de Tração e Curva de Potência (Wong, 2022)

Para garantir que o UGV vença rampas e escadas de inclinação $\theta = 35^\circ$ com massa total $M = 10{,}03\text{ kg}$ e velocidade de cruzeiro $v = 1,0\text{ m/s}$, calcula-se o esforço trativo total conforme *J. Y. Wong (Theory of Ground Vehicles, Cap. 3)*:

$$F_{tracao\_total} = W \sin\theta + f_r W \cos\theta + \frac{W}{g} a_x$$

| Parâmetro de Cálculo | Valor Considerado | Força Requerida |
| :--- | :--- | :--- |
| **Resistência de Subida ($W \sin 35^\circ$)** | $10\text{ kg} \cdot 9,81 \cdot \sin(35^\circ)$ | $56,2 \text{ N}$ |
| **Resistência ao Rolamento ($f_r W \cos 35^\circ$)** | $0,05 \cdot 98,1 \cdot \cos(35^\circ)$ | $4,0 \text{ N}$ |
| **Força de Aceleração Dinâmica ($m \cdot a_x$)** | $10\text{ kg} \cdot 0,5 \text{ m/s}^2$ | $5,0 \text{ N}$ |
| **Força Trativa Total Exigida ($F_{total}$)** | Somatório das forças resistentes | **$65,2 \text{ N}$** |
| **Torque Total nos 4 Eixos ($r_{roda} = 0,10\text{ m}$)** | $T_{total} = F_{total} \cdot r$ | **$6,52 \text{ N}\cdot\text{m}$** |
| **Torque Mínimo por Motorredutor (4WD)** | $T_{motor} = T_{total} / 4$ | **$1,63 \text{ N}\cdot\text{m} \ (16,3 \text{ kgf}\cdot\text{cm})$** |

> **Superado em R2.** A tabela acima usa $r_{roda} = 0,10$ m (o resto do projeto
> usava 0,15 m) e massa de 10 kg (o simulador usava 7,5 kg), e ignora o torque
> **geométrico de içamento** sobre o nariz do degrau, que é o caso dimensionante.
> Com o modelo completo: torque exigido de **6,44 N·m por roda**, redução
> **1:172**, stall de **12,49 N·m** e margem de **1,92**. Ver
> [`07_Orcamento_de_Tracao_Energia_e_Termica.md`](07_Orcamento_de_Tracao_Energia_e_Termica.md).

---

## 3. Odometria e Estimativa de Estado com Fusão Sensorial (Siegwart & Nourbakhsh, 2004)

O controlador embarcado executa um algoritmo de **Odometria e Dead-Reckoning** para calcular o deslocamento do rover no espaço e monitorar a integridade da carga útil (*Siegwart & Nourbakhsh, Cap. 4 e 5*):

```mermaid
graph LR
    subgraph Fusão Sensorial no ESP32
        E[Encoders de Roda 4WD] --> ODOM[Cálculo de Deslocamento Odométrico]
        I[Giroscópio / Acelerômetro IMU] --> KF[Filtro Complementar / Kalman]
        ODOM & I --> KF
        KF --> EST[Estimativa de Postura: x, y, theta + Pitch/Roll]
        EST --> PROT[Proteção Anti-Tombamento e Failsafe]
    end
```

1. **Cálculo Odométrico de Posição ($x, y, \theta$)**:
   $$\Delta x_k = v_{linear} \cdot \cos(\theta_k) \cdot \Delta t, \quad \Delta y_k = v_{linear} \cdot \sin(\theta_k) \cdot \Delta t$$
2. **Monitoramento Ativo de Inclinação (*Anti-Tipover Guard*)**:
   * O sensor IMU (BNO055 / MPU6050) mede continuamente os ângulos de *Pitch* e *Roll* da caixa organizadora.
   * **Intervenção Automática (corrigido em R2)**: o limiar de arfagem é
     **dependente de modo** — $35^\circ$ em piso e $52^\circ$ em modo escada.
     Um limiar único de $40^\circ$ abortaria toda subida: numa escada de $29{,}5^\circ$
     a oscilação da marcha de 3 raios leva o chassi a $\approx 43^\circ$ em
     **operação normal**. O tombamento estático longitudinal ocorre em $52{,}6^\circ$.
3. **Telemetria de Vibração da Carga (Notebook)**:
   * Registro contínuo dos picos de aceleração vertical ($a_z$). Se $a_z > 2,0g$, um aviso sonoro é enviado à tela FPV do piloto (*OSD*).

---

## 4. Sistema de Vídeo FPV de Latência Zero (< 20ms)

* **Câmera FPV Micro (1200 TVL com WDR)**: Instalada no terço superior frontal da caixa organizadora, oferecendo visão angular de $150^\circ$ do terreno e dos degraus.
* **Transmissor de Vídeo Analógico 5.8GHz 600mW (VTX)**: Transmite o sinal de vídeo diretamente para os óculos ou monitor do piloto sem compressão digital pesada, garantindo **latência $< 20\text{ milissegundos}$**. Isso é vital para que o piloto humano sinta a reação do UGV e ajuste o stick de controle com precisão milimétrica durante a subida de escadas.

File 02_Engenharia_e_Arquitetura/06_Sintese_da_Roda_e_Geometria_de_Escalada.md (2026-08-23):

# 06. Síntese da Roda e Geometria de Escalada
## Da fórmula de Blondel ao diâmetro da roda, com verificação numérica

> **Documento central da revisão R2.** Substitui a dedução de `05_Dimensionamento_Blondel`,
> que usava um critério de rolamento em piso plano para dimensionar uma roda que
> não rola — ela salta de degrau em degrau. Ver auditoria [A-01](../00_Especificacao_Mestre/02_Auditoria_Tecnica.md#a-01).

---

## 1. O problema, colocado corretamente

Uma roda de *N* raios não tem superfície contínua de rolamento. Sobre uma escada,
o movimento é uma sequência de **pivotamentos**: a roda gira em torno do ponto de
contato corrente até que outro raio toque a estrutura, e o contato se transfere.
São exatamente os dois estados descritos por Jeong & Kim (2025):

* **CCS** (*Continuous Contact State*) — o contato migra ao longo da curva de um
  mesmo raio; o raio efetivo cresce de `r_cubo` até `r_max` e o cubo sobe;
* **DCS** (*Discontinuous Contact State*) — o contato salta para o raio seguinte;
  o raio efetivo despenca e o cubo cai.

A pergunta de projeto não é "qual arco a roda percorre por volta", e sim:

> **O raio seguinte alcança o nariz do degrau seguinte?**

---

## 2. Condição de marcha síncrona

Sejam:

* $E$ o espelho e $P$ o piso do degrau;
* $D = \sqrt{E^2+P^2}$ o **passo nariz-a-nariz** (a distância entre arestas de
  degraus consecutivos);
* $N$ o número de raios, defasados de $2\pi/N$;
* $r_{max}$ o raio da ponta do raio.

No instante da transferência ideal, dois raios consecutivos tocam dois narizes
consecutivos. O cubo está a distância $r_1$ de um e $r_2$ do outro, com ângulo
$2\pi/N$ entre eles. Pela lei dos cossenos:

$$D^2 = r_1^2 + r_2^2 - 2\,r_1 r_2 \cos\!\left(\frac{2\pi}{N}\right)$$

Esse valor é máximo quando ambos os contatos ocorrem na ponta
($r_1 = r_2 = r_{max}$), o que dá a corda do polígono regular inscrito:

$$D_{max} = 2\,r_{max}\sin\!\left(\frac{\pi}{N}\right)$$

Logo, a **condição necessária de marcha síncrona** (um degrau por raio):

$$\boxed{\;D \;\le\; 2\,r_{max}\sin\!\left(\frac{\pi}{N}\right)
\qquad\Longleftrightarrow\qquad
r_{max}\;\ge\;\frac{D}{2\sin(\pi/N)}\;}\tag{1}$$

### 2.1. Aplicação ao degrau de referência

Para $E = 170$ mm e $P = 300$ mm (2E+P = 64 cm, conforme NBR 9050):

$$D = \sqrt{170^2+300^2} = 344{,}8\ \text{mm}, \qquad \theta = \arctan(E/P) = 29{,}5^\circ$$

| $N$ | $r_{max}$ mínimo | $\Phi$ mínimo |
| ---: | ---: | ---: |
| **3** | **199,1 mm** | **398 mm** |
| 4 | 243,8 mm | 488 mm |
| 5 | 293,3 mm | 587 mm |
| 6 | 344,8 mm | 690 mm |

> **N = 3 é o mínimo global.** Como $\sin(\pi/N)$ decresce com $N$, mais raios
> exigem rodas **maiores** para a mesma escada. Essa é a justificativa quantitativa
> para os três raios de Jeong & Kim — que R1 adotava sem demonstrar.

### 2.2. Por que a roda de R1 não sobe

A roda original ($N=3$, $r_{max}=150$ mm) tem alcance

$$2 \times 150 \times \sin 60^\circ = 259{,}8\ \text{mm} \;<\; 344{,}8\ \text{mm}$$

**Déficit de 85 mm.** O raio seguinte não alcança o nariz seguinte: o cubo desce
para dentro do degrau e o raio acaba apoiando na **face vertical do espelho**,
onde a reação necessária sai do cone de atrito. A roda escorrega em vez de subir.

---

## 3. Do critério analítico ao projeto: robustez de fase

A Equação (1) é **necessária, não suficiente**. Ela garante que o alcance existe,
mas não que o engate aconteça a partir de qualquer posição de chegada. E a fase
com que o rover encontra o primeiro degrau **não é controlável pelo piloto**.

Por isso o dimensionamento final é feito por varredura: para cada candidato,
simula-se a marcha a partir de 12 fases de aproximação distribuídas ao longo de
um passo completo, em todas as escadas da família de Blondel.

```bash
python3 -m simulador_python.main --sintese
```

| $\Phi$ [mm] | E16/P32 | E17/P30 | E18/P28 | pior caso |
| ---: | ---: | ---: | ---: | ---: |
| 300 (R1) | 0% | 0% | 0% | **0%** |
| 360 | 50% | 50% | 58% | 50% |
| 400 | 75% | 83% | 92% | 75% |
| **420 (adotado)** | **100%** | **100%** | **100%** | **100%** ✔ |
| 440 | 100% | 100% | 100% | 75%¹ |
| 460 | 83% | 75% | 83% | 75% |
| 480 | 67% | 58% | 42% | 42% |

¹ falha nas escadas fora de norma mais curtas (E16/P28).

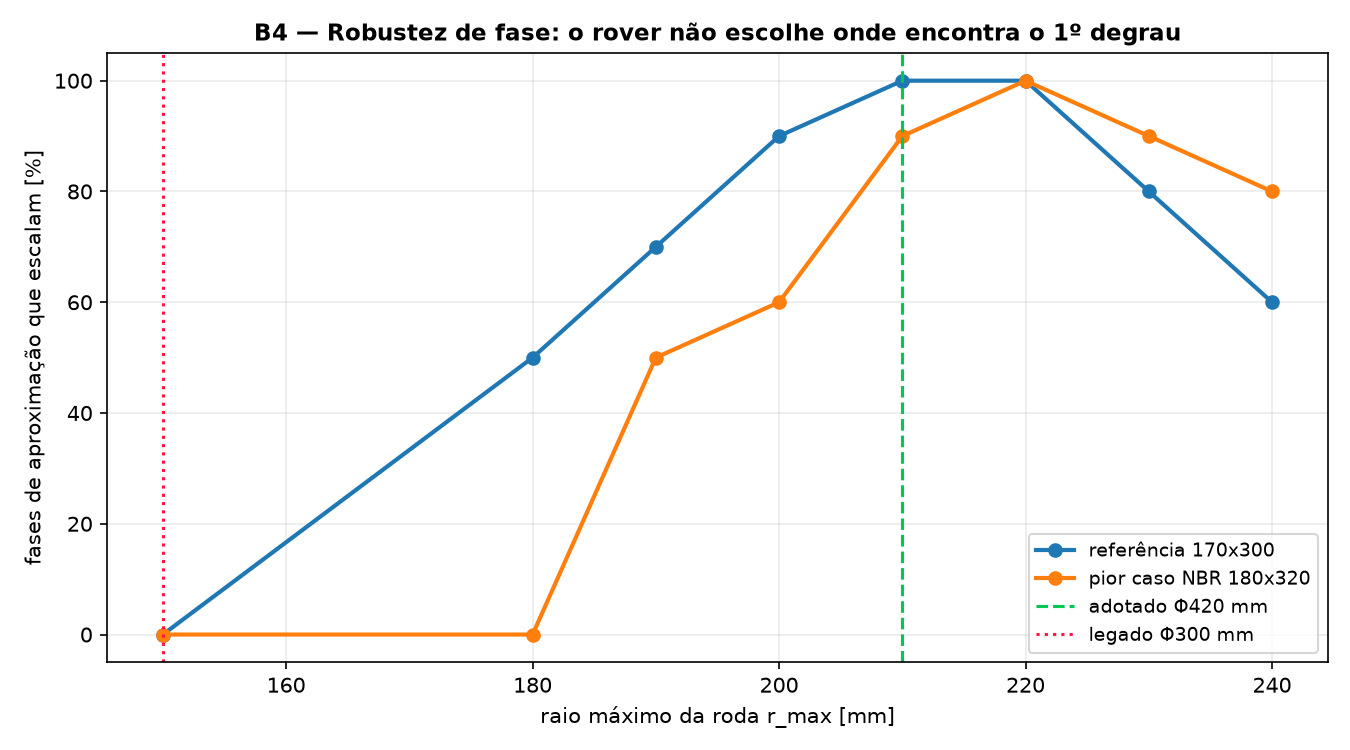
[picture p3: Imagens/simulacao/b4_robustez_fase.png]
Robustez de fase


> **O sucesso não é monotônico no raio.** Subdimensionar trava na face do
> espelho; **sobredimensionar** faz a roda ultrapassar o nariz e cair dentro do
> degrau. Existe um ótimo, e ele é **Φ 420 mm**.

**Parâmetros adotados:** $N = 3$, $r_{max} = 210$ mm, $r_{cubo} = 70$ mm.

---

## 4. Consequências geométricas do dimensionamento

### 4.1. Entre-eixos travado em fase com a escada

Se o entre-eixos for múltiplo inteiro do passo do degrau, os eixos dianteiro e
traseiro engatam **em fase** e a arfagem do chassi oscila menos:

$$L = k \cdot D = 2 \times 344{,}8 = 689{,}6 \approx \mathbf{690\ mm}$$

### 4.2. Vão livre do ventre

Dois critérios independentes, vale o maior:

| Critério | Valor |
| :--- | ---: |
| (a) folga até a linha dos narizes na subida (medida na marcha) | 210 − 79 + 20 = 151 mm |
| (b) aproximação frontal do primeiro degrau: ventre > espelho + margem | 170 + 20 = **190 mm** |

**Adotado: 190 mm** — critério (b) domina.

### 4.3. Torque de içamento

O torque exigido no eixo é o momento da carga em relação ao ponto de contato:

$$T = F_z \cdot \max\!\left(0,\; x_{contato} - x_{cubo}\right)$$

A hipótese de carga correta: **na subida a transferência de carga é para trás**,
portanto quem faz o esforço são as rodas **traseiras**.

$$F_{z,tras} = W\left(\frac{l_f}{L}\cos\theta + \frac{h_{CG}}{L}\sin\theta\right)
= 61{,}6\ \text{N (eixo)} \Rightarrow 30{,}8\ \text{N por roda}$$

Envelope do torque de pico sobre toda a família de escadas e todas as fases:
**T = 6,44 N·m por roda** — é este valor que dimensiona a redução do motorredutor
(cap. 07) e a rigidez do C-STS (§5).

### 4.4. Queda de cubo e o curso da suspensão

A marcha síncrona tem um preço inescapável: entre transferências, o cubo cai

$$\Delta y \approx r_{max}\left(1-\cos\frac{\pi}{N}\right) = 210 \times 0{,}5 = 105\ \text{mm}$$

O valor medido na escada é de **89 mm** (o aro elástico e a inclinação reduzem
um pouco). Absorver essa energia dentro do limite de 2,0 g exige **90 mm de curso
de suspensão** — e não os 35 mm de R1. Ver [A-03](../00_Especificacao_Mestre/02_Auditoria_Tecnica.md#a-03).

---

## 5. Dimensionamento do C-STS por semelhança dimensional

A rigidez torsional da mola espiral plana e a tensão de flexão na lâmina:

$$k_t = \frac{E\,b\,t^3}{12\,L}, \qquad \sigma = \frac{6M}{b\,t^2},
\qquad L \approx \pi\,n\,(r_i + r_o)$$

O procedimento **inverte** a relação: em vez de copiar o $k_t$ do artigo, parte-se
do requisito.

1. **Rigidez de projeto:** $k_t = T_{projeto} / \Delta\theta_{adm} = 5{,}40 / \text{30}^\circ = 10{,}31$ N·m/rad
2. **Compensação do FDM:** $k_{t,teórico} = k_t / 0{,}828 = 12{,}46$ N·m/rad
   — o fator 0,828 é a razão entre rigidez experimental e teórica medida por
   Jeong & Kim, e reflete a aderência parcial entre filetes. **Esse** é o
   resultado transferível do artigo, não o valor absoluto de $k_t$.
3. **Geometria:** resolve-se $t$ para cada número de voltas $n$, aceitando a
   primeira solução que caiba na banda radial do cubo e satisfaça FS ≥ 2.

```
C-STS em PETG: b=30,0 mm, t=10,30 mm, L=386 mm, 1,5 voltas (r 20→62 mm)
  kt teórico / efetivo ..... 12,46 / 12,30 N·m/rad
  tensão de flexão ......... 12,1 MPa (FS = 4,1)
  energia no pico .......... 1,69 J
  massa .................... 143 g
```

Comparação com a cópia direta do artigo:

| | Jeong & Kim (escala do artigo) | Este projeto |
| :--- | ---: | ---: |
| $k_t$ | 0,547 N·m/rad | **12,30 N·m/rad** |
| Deflexão sob T = 6,44 N·m | 566° (enrola por completo) | **30°** ✔ |
| Espessura da lâmina | 5,0 mm | **10,30 mm** |

---

## 6. O aro elástico: item crítico, não acessório

Sem aro, a roda de 3 raios é uma *rimless wheel* e o cubo oscila **105 mm em piso
plano** — a cada 120° de rotação. A missão é majoritariamente piso plano.

```mermaid
graph TD
    subgraph "Tensão de projeto"
        A["Piso plano quer MUITOS raios<br/>ripple = r·(1-cos(π/N))<br/>ripple < 5 mm exige N ≥ 14"]
        B["Escada quer POUCOS raios<br/>r_max = D / (2·sin(π/N))<br/>N = 3 minimiza o raio"]
    end
    A -->|conflito direto| C
    B -->|conflito direto| C
    C["<b>Aro elástico</b><br/>superfície contínua no plano,<br/>colapso local na quina do degrau"]
    C --> D["N = 3 com rolamento suave:<br/>0,58 g no plano, 0,81 g na escada"]
```

**Como funciona.** Em superfície contínua o aro sustenta o veículo a
$r_{max}$ menos a deflexão estática ($\approx 6$ mm sob 21 N), e o rover rola como
uma roda convencional. Ao encontrar a quina de um degrau, a carga se concentra num
ponto e o aro **colapsa localmente**, expondo a ponta do raio, que engata no
nariz.

**Especificação e o que ainda precisa ser medido:**

| Parâmetro | Valor de projeto | Como verificar |
| :--- | ---: | :--- |
| Rigidez radial | 3500 N/m | ENS-04: carga x deflexão em bancada |
| Curso até colapso | 25 mm | ENS-04 |
| Força de colapso local | 90 N | ENS-04: célula de carga contra aresta viva |
| Massa por roda | 90 g | pesagem |

> **Risco em aberto.** A janela entre "rígido o bastante para carregar no plano" e
> "macio o bastante para colapsar na quina" ainda não foi medida fisicamente. Se
> a janela for estreita demais na prática, a alternativa é aro segmentado com
> molas de lâmina — mecanismo clássico de Sclater & Chironis, cap. 10.
> Este é o **maior risco técnico remanescente** do projeto (ver FMEA, `09`).

---

## 7. Verificação

```bash
python3 -m simulador_python.main --marcha    # marcha na escada de referência
python3 -m simulador_python.main --sintese   # varredura do espaço de projeto
python3 -m pytest testes/test_geometria_escada.py -v
```

O simulador de marcha (`simulador_python/geometria_escada.py`) resolve o
movimento por **eventos de contato**, sem nenhum fator de ajuste: pivota em torno
do contato corrente, isola por bisseção o instante em que outro ponto da roda toca
o terreno e transfere o pivô. Limitações e domínio de validade do modelo estão em
[`03_Simulacao/04_Verificacao_e_Validacao_do_Modelo.md`](../03_Simulacao_e_Prototipacao_Digital/04_Verificacao_e_Validacao_do_Modelo.md).

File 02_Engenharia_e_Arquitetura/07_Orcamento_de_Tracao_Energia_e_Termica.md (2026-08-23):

# 07. Orçamento de Tração, Energia e Térmica
## Curva real do motorredutor, pack de bateria e o limite que ninguém tinha visto

> Substitui o dimensionamento de `04_Eletronica_Controle_e_Potencia` §2, que
> usava r = 0,10 m para a roda (o resto do projeto usava 0,15 m) e massa de 10 kg
> (o simulador usava 7,5 kg). Ver [A-07](../00_Especificacao_Mestre/02_Auditoria_Tecnica.md#a-07).

---

## 1. Modelo do motorredutor

Motor CC de ímã permanente com redutor planetário metálico:

$$T_{rotor} = K_t\,(I - I_0), \qquad I = \frac{V - K_e\,\omega_{rotor}}{R_a},
\qquad K_t = K_e = \frac{60}{2\pi K_v}$$

$$T_{saida} = T_{rotor}\cdot i \cdot \eta_{red}, \qquad
\omega_{saida} = \frac{\omega_{rotor}}{i}$$

| Parâmetro | Valor | Origem |
| :--- | ---: | :--- |
| Tensão nominal | 12,0 V | pack 4S LiFePO4 |
| $K_v$ | 1000 rpm/V | classe 550 |
| $R_a$ | 1,10 Ω | catálogo |
| $I_0$ (a vazio) | 0,35 A | catálogo |
| **Redução $i$** | **1:172** | valor de catálogo, dimensionado aqui |
| $\eta_{red}$ | 0,72 | trem planetário de 3 estágios |
| **Torque de stall na saída** | **12,49 N·m** | calculado |
| **Rotação a vazio na saída** | **69,8 rpm** (1,53 m/s) | calculado |

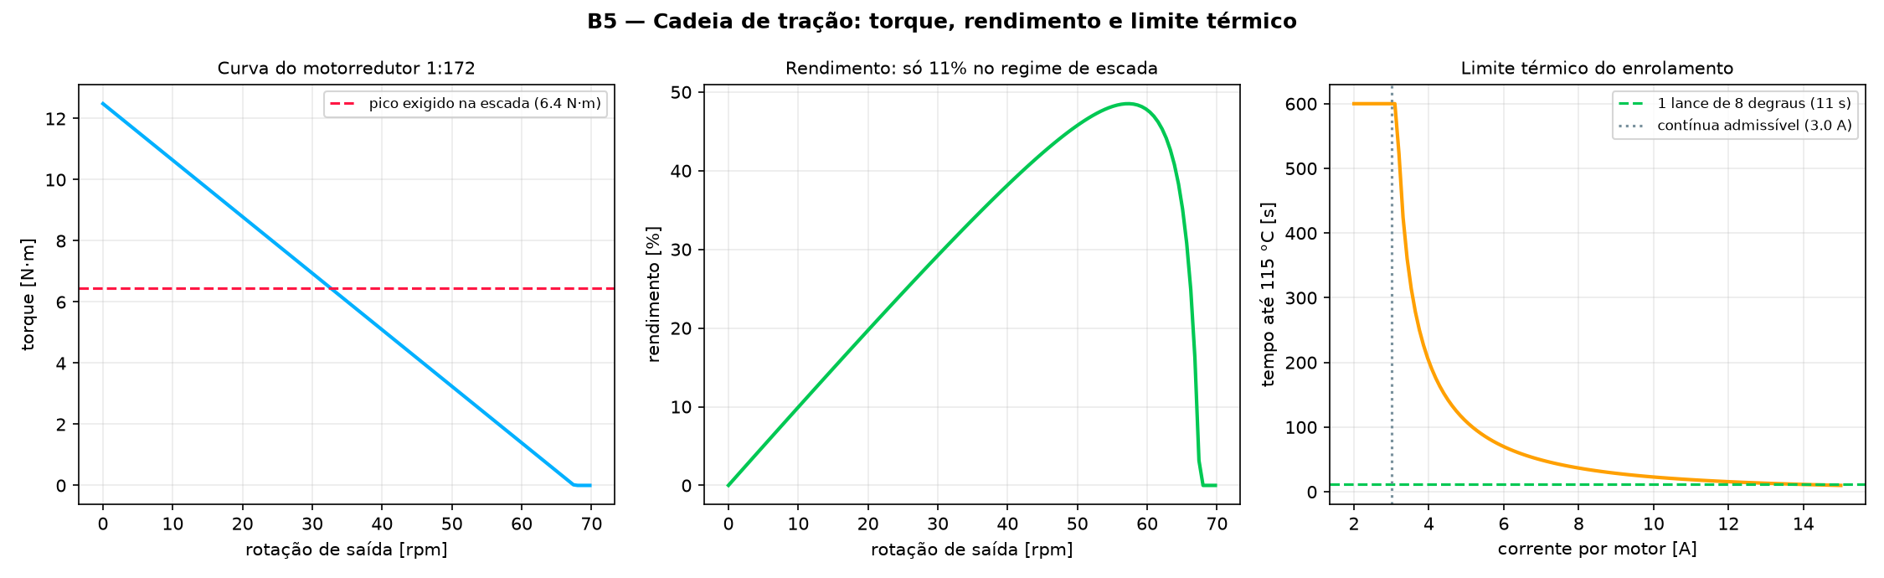
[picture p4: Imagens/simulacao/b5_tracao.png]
Cadeia de tração


### 1.1. Por que 1:172

O torque exigido no pior caso é **6,44 N·m por roda** (§4.3 do documento 06). Na
velocidade de escada (0,25 m/s → 1,14 rad/s na saída, 16% da rotação a vazio) o
motor entrega ~84% do stall:

| Redução | Stall na saída | Disponível a 0,25 m/s | Margem | $v_{max}$ |
| ---: | ---: | ---: | ---: | ---: |
| 1:100 | 7,26 N·m | 6,55 N·m | 1,02 ✘ | 2,64 m/s |
| 1:131 | 9,51 N·m | 8,29 N·m | 1,29 ✘ | 2,01 m/s |
| **1:172** | **12,49 N·m** | **10,38 N·m** | **1,61** ✔ | **1,53 m/s** |
| 1:270 | 19,60 N·m | 14,42 N·m | 2,24 ✔ | 0,98 m/s ✘ |

1:131 **não** atende (1,29 < 1,50) depois da correção de massa do achado A-21 —
o que mostra por que a margem de KPI existe. **1:172** é a escolha: margem de
**1,61** e ainda 1,53 m/s de velocidade máxima, acima da meta de 1,0 m/s. 1:270
daria mais margem de torque, mas sacrificaria a velocidade em terreno plano —
que é 95% da missão.

---

## 2. Pack de bateria

| Parâmetro | Valor |
| :--- | ---: |
| Configuração | 4S2P LiFePO4 |
| Tensão nominal / cheia / corte | 12,8 / 14,6 / 11,2 V |
| Capacidade | 6,0 Ah |
| Energia total / útil (reserva 20%) | 76,8 / 61,4 Wh |
| Resistência interna do pack | 50 mΩ |

**Escolha da química.** LiFePO4 em vez de LiPo: a diferença de densidade
energética não é limitante aqui (a missão usa 15% da energia), enquanto a
segurança térmica, a vida em ciclos e a tolerância a carga mal feita — num
laboratório compartilhado com bolsistas — são vantagens diretas.

**Requisito derivado (REQ-303):** a corrente de pico é **27,7 A = 4,6C**. Células
de 3 Ah precisam suportar ≥ 5C contínuo. Nem toda célula LiFePO4 de 26650 atende:
**verificar no datasheet antes de comprar.**

---

## 3. Orçamento da missão de homologação

Percurso completo de `05_Execucao/03`, integrado trecho a trecho:

| Trecho | Dist. | Dur. | Torque/roda | Margem | Corrente | Energia |
| :--- | ---: | ---: | ---: | ---: | ---: | ---: |
| Base → calçada (asfalto) | 180 m | 188 s | 0,14 N·m | 53,1 | 1,9 A | 1,76 Wh |
| Rampa de acessibilidade (8%) | 25 m | 37 s | 0,52 N·m | 18,7 | 3,2 A | 0,54 Wh |
| Calçada de paver | 120 m | 125 s | 0,21 N·m | 35,0 | 2,1 A | 1,29 Wh |
| Meio-fio + soleira | 6 m | 20 s | 3,57 N·m | 3,6 | 13,5 A | 1,07 Wh |
| Corredor interno | 60 m | 104 s | 0,10 N·m | 110,1 | 1,7 A | 0,90 Wh |
| Embarque do notebook | — | 10 s | — | — | 1,9 A | 0,09 Wh |
| Retorno com carga | 150 m | 156 s | 0,21 N·m | 34,3 | 2,1 A | 1,60 Wh |
| **Escada de 8 degraus** | 2,8 m | 11 s | **7,78 N·m** | **1,67** | **27,7 A** | 1,14 Wh |
| Corredor até a T.I. | 45 m | 78 s | 0,10 N·m | 108,5 | 1,7 A | 0,67 Wh |
| **TOTAL** | **589 m** | **12,2 min** | — | **1,67** | pico 27,7 A | **9,1 Wh** |

* Consumo: **15% da energia útil** — a missão não é limitada por energia.
* Autonomia em ciclo misto (75% plano, 20% rampa, 5% escada): **60 min**
  (KPI ≥ 30 min, meta 45) ✔

---

## 4. O limite real da escada é térmico

Na escada o ponto de operação fica a **~11% de rendimento**: quase toda a
potência elétrica vira calor ôhmico no enrolamento.

Modelo térmico de primeira ordem (enrolamento → ambiente):

$$T(t) = T_\infty + (T_0 - T_\infty)\,e^{-t/\tau},
\qquad T_\infty = T_{amb} + I^2 R_a R_{th}, \qquad \tau = R_{th}C_{th}$$

Com $R_{th} = 8$ K/W, $C_{th} = 30$ J/K ($\tau = 240$ s), $T_{amb} = 35$ °C
(pior caso de verão em Foz do Iguaçu) e limite de classe de 115 °C:

| Corrente/motor | Regime | Tempo até 115 °C |
| ---: | ---: | ---: |
| **3,02 A** | 115 °C | **∞ — corrente contínua admissível** |
| 5,0 A | 255 °C | 108 s |
| 6,9 A | 457 °C | 50 s |
| **9,2 A (escada)** | 781 °C | **27 s** |
| 13,5 A (meio-fio) | 1639 °C | 12 s |

> **Um lance de 8 degraus a 0,25 m/s leva ~11 s.** Cabe. **Dois lances
> consecutivos sem pausa consomem quase toda a margem térmica.** Um prédio de
> três andares — situação perfeitamente plausível no Parquetec — **não é
> executável sem pausas de resfriamento**.

**Requisitos derivados:**

* **REQ-304** — proteção I²t no firmware, com modelo térmico embarcado
  (não basta desarmar por corrente instantânea: o dano é integral).
* **REQ-305** — pausa de resfriamento obrigatória entre lances, com o tempo
  calculado pelo modelo e exibido ao piloto.
* Sensor de temperatura (NTC) colado na carcaça de pelo menos um motor,
  para calibrar $R_{th}$ e $C_{th}$ no ENS-13 e substituir a estimativa.

---

## 5. Dimensionamento elétrico consolidado

```mermaid
graph TD
    BAT["Pack 4S2P LiFePO4<br/>12,8 V · 6,0 Ah · 77 Wh<br/>R_int = 50 mΩ"] --> BMS["BMS 4S com balanceamento<br/>corte por célula e por temperatura"]
    BMS --> FUS["Fusível 40 A + chave E-Stop<br/>(pico medido: 27,7 A)"]
    FUS --> PDB["Placa de distribuição"]
    PDB --> DRV["2x ponte H dupla BTS7960<br/>≥ 20 A/canal com dissipador"]
    PDB --> BK5["Buck 5 V / 5 A — lógica e rádio"]
    PDB --> BK6["Buck 6,0 V / 10 A — 4 servos 4WS"]
    DRV --> MOT["4x motorredutor 12 V 1:172<br/>com encoder"]
    BK5 --> MCU["ESP32-S3 dual-core"]
    MCU --> IMU["IMU BNO055"]
    MCU --> NTC["NTC nos motores<br/>(modelo térmico I²t)"]
    MCU --> ENC["Encoders — ver nota do C-STS"]
```

> **Nota sobre encoders e o C-STS.** Sob torque nominal a roda **atrasa 30°** em
> relação ao eixo do motor (é essa a função da mola). Encoder no motor mede o
> motor, não a roda. Duas saídas: encoder magnético no lado da roda, ou
> compensação explícita $\theta_{roda} = \theta_{motor} - T/k_t$ no firmware.
> Sem uma das duas, a odometria acumula erro sistemático em toda subida.

---

## 6. Reprodução

```bash
python3 -c "
from simulador_python.powertrain import *
o = OrcamentoEnergia()
r = o.avaliar_missao(missao_parquetec())
print('energia %.1f Wh, margem mínima %.2f, pico %.1f A' %
      (r['energia_total_wh'], r['margem_torque_minima'], r['corrente_pico']))
print(o.autonomia_ciclo_misto())"

python3 -m pytest testes/test_powertrain.py -v
```

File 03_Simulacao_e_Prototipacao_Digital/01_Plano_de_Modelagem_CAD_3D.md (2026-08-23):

# 01. Plano de Modelagem CAD 3D e Engenharia de Manufatura Aditiva
## Parametrização de Peças, Juntas de PVC e Diretrizes de Impressão 3D

> [!IMPORTANT]
> **Revisão R2 — atualizado**
> O catálogo de peças descrevia a roda com **4 raios** (o resto do projeto usa 3) e o anel de banda de rodagem como **opcional** (ele é crítico — sem aro o cubo cai 105 mm por raio em piso plano). Corrigido no texto; ver [A-02](../00_Especificacao_Mestre/02_Auditoria_Tecnica.md#a-02) e [A-13](../00_Especificacao_Mestre/02_Auditoria_Tecnica.md#a-13).
>
> Parâmetros vigentes: [`00_Especificacao_Mestre/00_Parametros_Mestres.md`](../00_Especificacao_Mestre/00_Parametros_Mestres.md) ·
> Achados: [`02_Auditoria_Tecnica.md`](../00_Especificacao_Mestre/02_Auditoria_Tecnica.md)

---

---

## 1. Fluxo de Trabalho de Modelagem Paramétrica CAD

Toda a modelagem geométrica do rover é estruturada em software CAD 3D paramétrico (como Onshape, Autodesk Fusion 360 ou FreeCAD), garantindo exportação universal em formatos abertos (**STEP, IGES e STL/3MF**).

```mermaid
graph LR
    subgraph Fluxo Digital CAD
        P[Esboço Paramétrico Global] --> M1[Módulo Juntas de PVC]
        P --> M2[Módulo Roda Curved Spokes]
        P --> M3[Módulo Clamps Caixa Organizadora]
        P --> M4[Módulo Suporte de Motores & Servos]
        M1 & M2 & M3 & M4 --> ASM[Montagem Virtual Completa / Assembly]
        ASM --> EXP[Exportação STL / STEP / URDF]
    end
```

---

## 2. Catálogo de Componentes Customizados para Impressão 3D
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

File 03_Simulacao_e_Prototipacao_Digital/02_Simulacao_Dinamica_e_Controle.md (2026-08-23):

# 02. Simulação Dinâmica, Cinemática Inversa e Física de Contato
## Cinemática inversa, física de contato e matriz de cenários

> [!IMPORTANT]
> **Revisão R2 — implementado**
> Este documento descrevia a intenção de simular em "Webots/Gazebo" com
> "URDF/SDF", sem que existisse URDF, mundo ou pacote. A implementação real está
> em [`ros2_ws/`](../ros2_ws/) e as decisões de modelagem em
> [`05_ROS2_e_Gazebo.md`](05_ROS2_e_Gazebo.md). A ferramenta foi decidida:
> **ROS 2 Jazzy + Gazebo Harmonic** (a justificativa está em `05`, §1); as
> menções a Webots foram removidas para não sugerir duas cadeias paralelas.
>
> A matriz de cenários de teste abaixo continua válida, agora com mundos
> executáveis correspondentes.

---

---

## 1. Algoritmo de Cinemática Inversa 4WS/4WD na Simulação

Para comandar os 8 atuadores no simulador virtual a partir dos comandos do joystick do piloto (velocidade longitudinal $v_x$, velocidade lateral $v_y$ e velocidade angular de guinada $\omega_z$), implementa-se o modelo analítico fechado de **Cinemática Inversa (*Siegwart & Nourbakhsh, 2004*)**:

Para cada roda $i \in \{1, 2, 3, 4\}$ posicionada nas coordenadas relativas $(x_i, y_i)$:
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

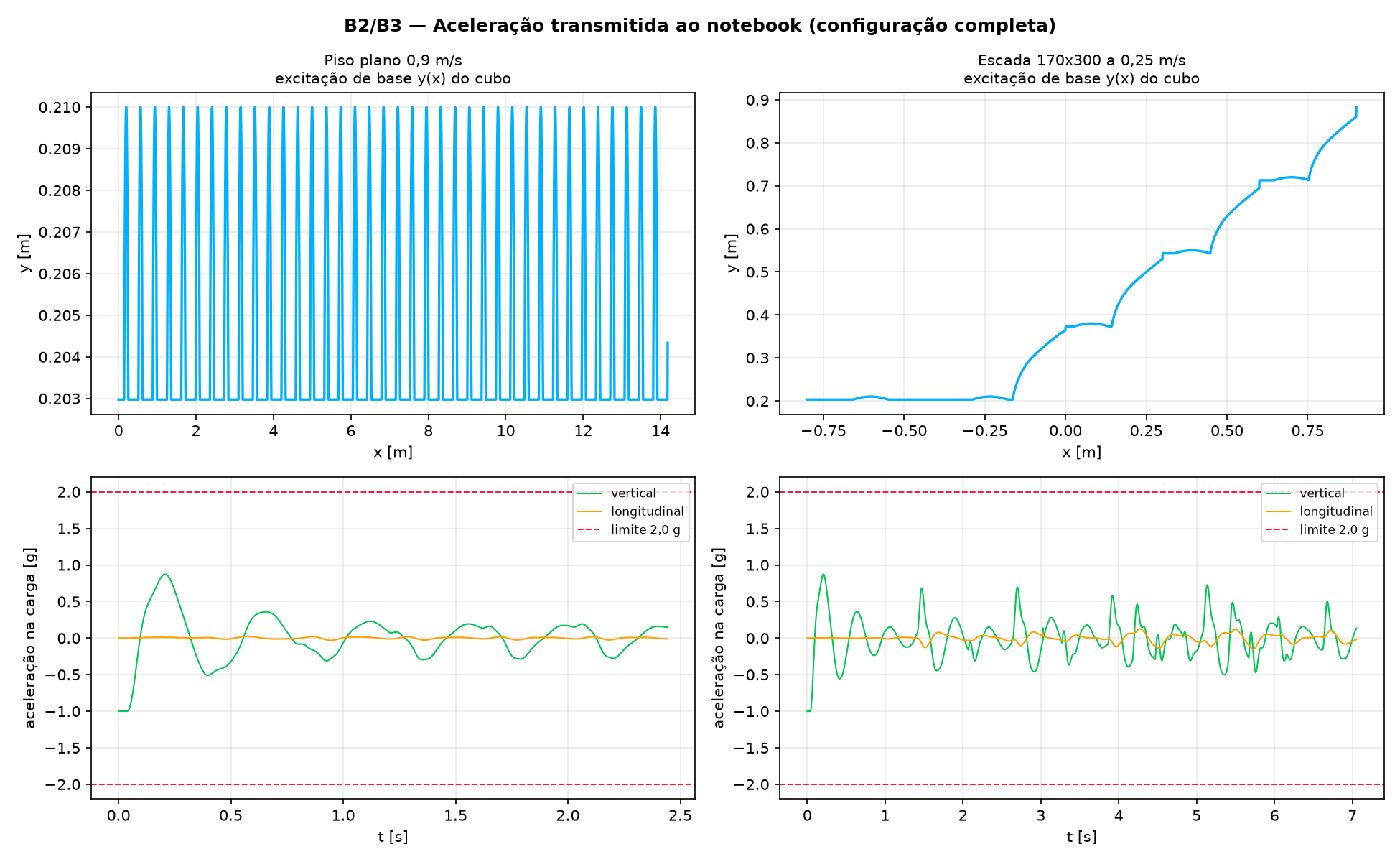
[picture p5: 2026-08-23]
Imagens/simulacao/b2_b3_suspensao.png

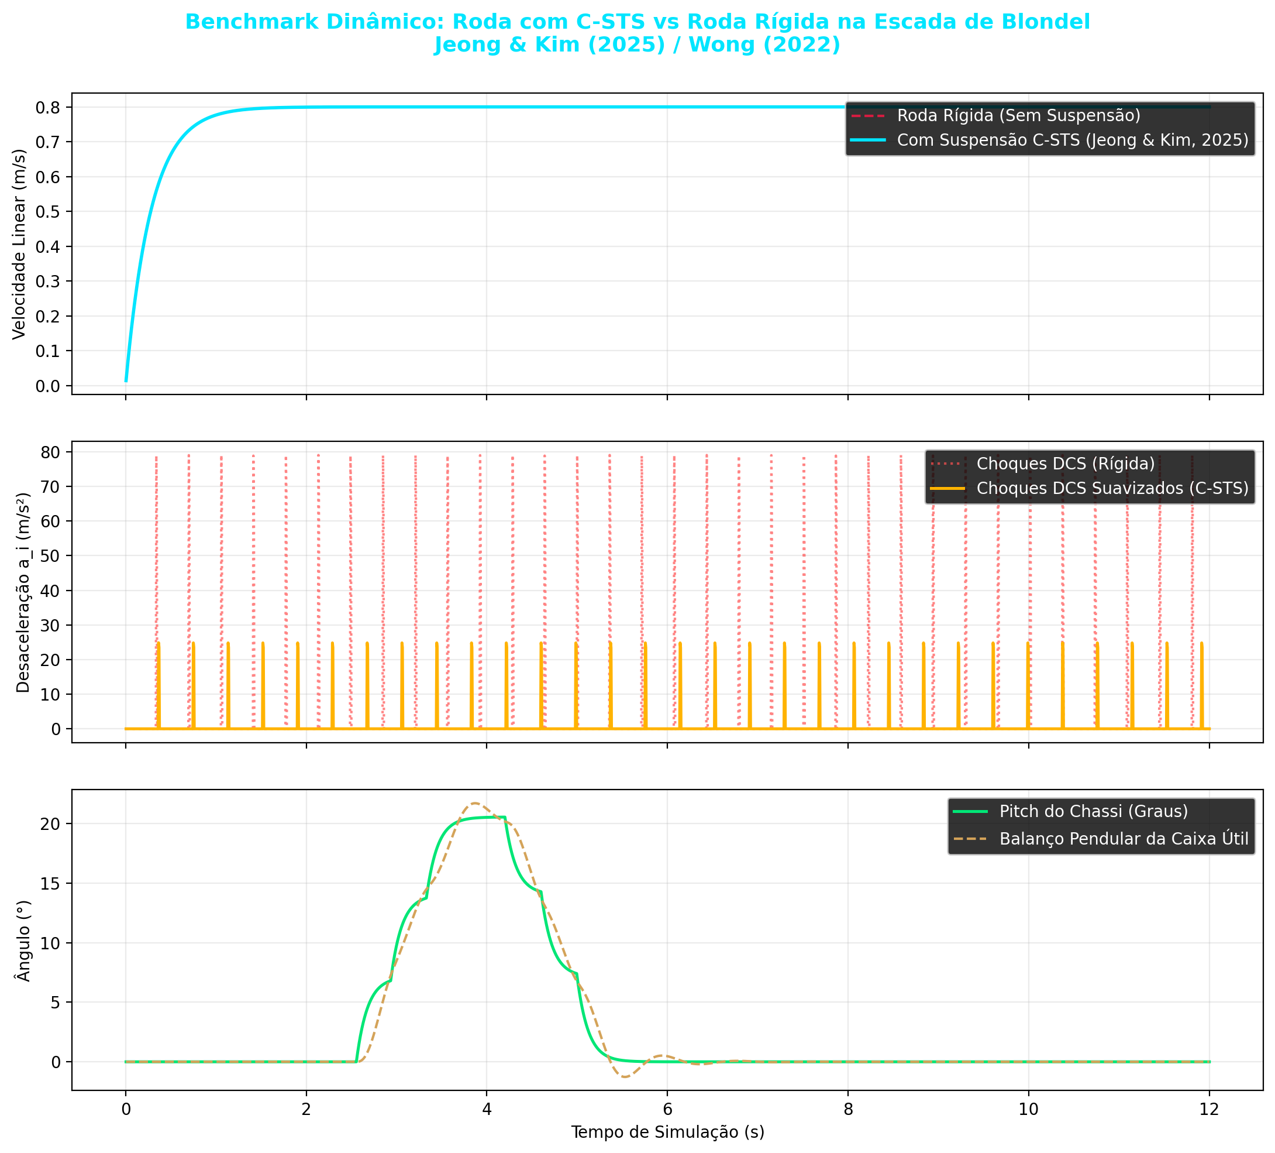
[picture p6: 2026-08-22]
Imagens/comparativo_csts_blondel.png

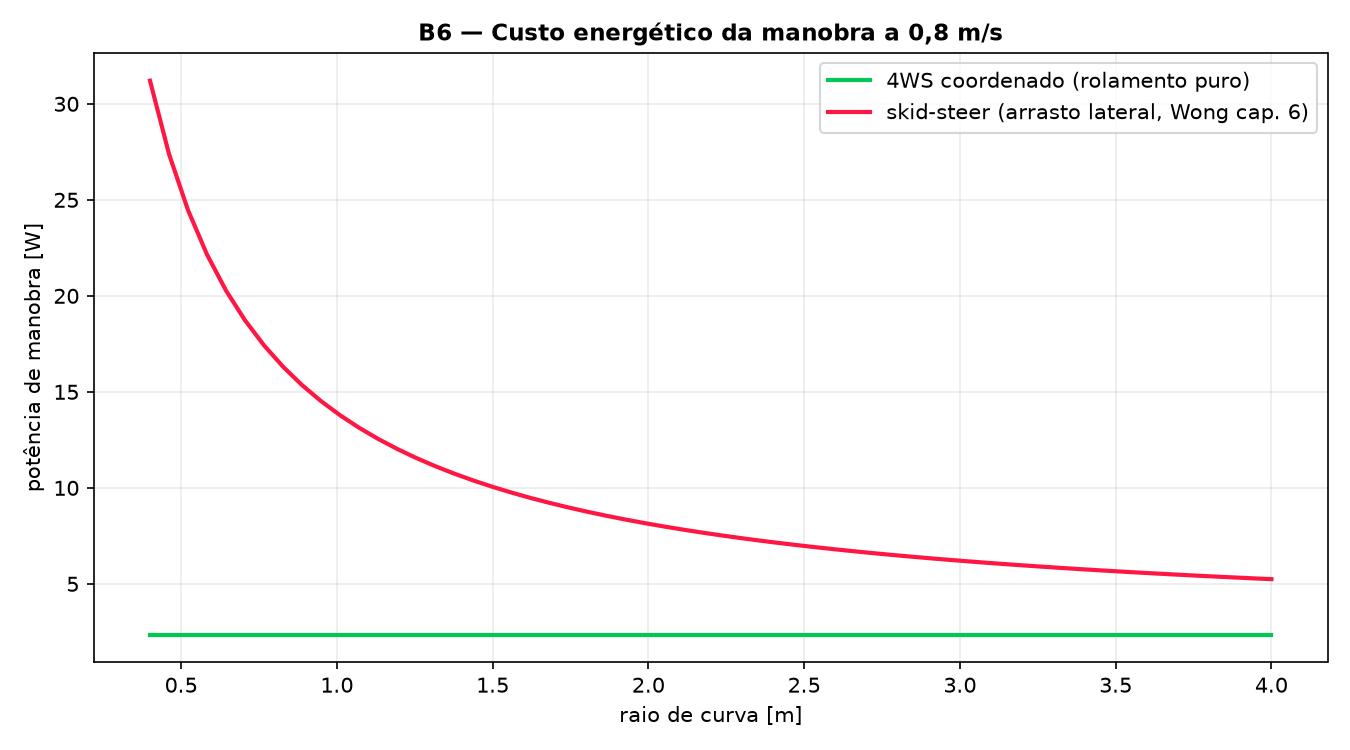
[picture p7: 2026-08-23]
Imagens/simulacao/b6_manobra.png

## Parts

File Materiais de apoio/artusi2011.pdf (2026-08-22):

50 | IEEE/ASME TRANSACTIONS ON MECHATRONICS, VOL. 16, NO. 1, FEBRUARY 2011

# Electroactive Elastomeric Actuators for the Implementation of a Deformable Spherical Rover

Matteo Artusi, Member, IEEE, Marco Potz, Member, IEEE, Jeydmer Aristizabal, Member, IEEE, Carlo Menon, Silvio Cocuzza, Member, IEEE, and Stefano Debei

Abstract—This paper presents investigations toward the development of an inflated deformable rolling rover. The proposed novel locomotion system could find potential future use, for example, in scouting and exploration missions. The manufacturing procedure used to fabricate a preliminary prototype is presented in this paper. The prototype consists of a rigid frame and four dielectric elastomer actuator (DEA) sectors, which give the prototype a spherical shape. Analytical models are proposed to predict the electromechanical behavior of the DEA sectors and to estimate their effect on the prototype’s dynamics. These models are validated through an experimental procedure.

Index Terms—Concept design, dielectric elastomers, electroactive polymers, rover, smart materials, spherical robot.

I. INTRODUCTION

SPHERICAL rovers have been investigated in recent years [1]–[7] for exploration tasks in different environments, including the outer space. In planetary space explorations, the rover should be lightweight and have low volume in order to reduce the otherwise prohibitive costs of the launch phase. To fulfill these requirements, different innovative propulsion systems for spherical rovers have been developed; for instance, it was proposed that the motion could be generated by an external power source (e.g., wind energy [1]), by the motion of one or more ballasts [2]–[4], or by the deformation of the rover’s structure [7].
In this paper, a novel spherical rover, whose external surface deforms upon electrical stimuli, is proposed. The deformation of such an external surface changes the centre of gravity (CG) of the rover, which causes the rover to roll. Differently from previous studies, the external surface consists of an array of dielectric elastomer actuator (DEA) sectors, which can change shape according to the intensity of an imposed electrical field

Manuscript received April 1, 2010; revised July 9, 2010; accepted October 15, 2010. Date of publication January 7, 2011; date of current version January 12, 2011. Recommended by Guest Editor R. Kornbluh. This work was supported by the Natural Sciences and Engineering Research Council of Canada, Ottawa, ON, Canada.
Artusi and M. Potz are with the Menrva Research Group, School of Engineering Science, Simon Fraser University, Burnaby, BC V5A 1S6, Canada, and also with the CISAS, University of Padua, 35131 Padova, Italy.
J. Aristizabal and C. Menon are with the Menrva Research Group, School of ´ Engineering Science, Simon Fraser University, Burnaby, BC V5A 1S6, Canada (e-mail: carlo_menon@sfu.ca).
S. Cocuzza and S. Debei are with the CISAS, University of Padua, 35131 Padova, Italy.
Color versions of one or more of the figures in this paper are available online at http://ieeexplore.ieee.org.
Digital Object Identifier 10.1109/TMECH.2010.2090163

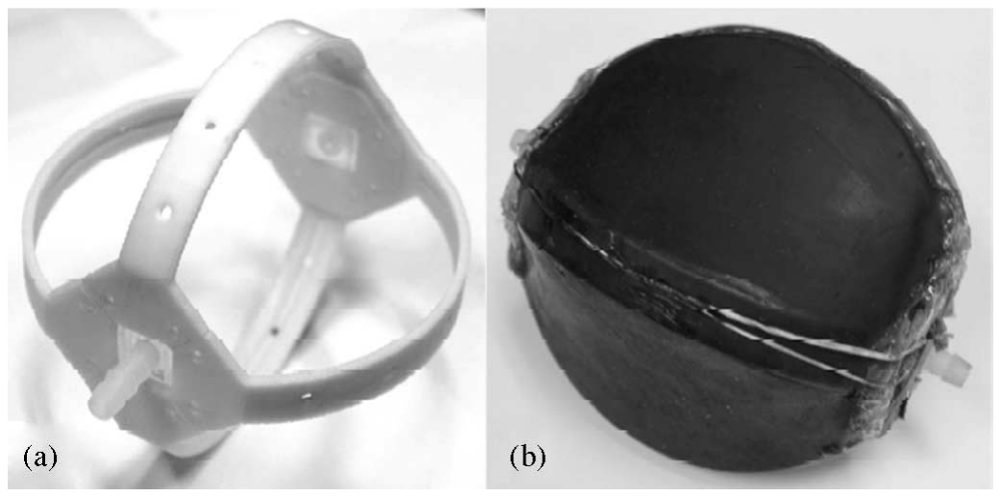
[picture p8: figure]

Fig. 1. (a) Internal rigid frame. (b) Prototype (not inflated) covered with DEA sectors.

[8]–[11]. The proposed novel spherical rover is inflated to enable prestretching and, therefore, high performance of the DEA array. This paper is organized as follows. Section II introduces the working principle on which the rover is based on and also outlines features that the developed preliminary prototype has. Section III investigates the behavior of the hyperelastic polymer that was used to manufacture the DEAs. Section IV introduces a simplified analytical model developed to predict the dynamic response of the external surface of the prototype; this section also presents an experimental validation of the proposed model. Section V presents both analytical and experimental analyses to estimate the potential rolling performance of the developed prototype. Conclusions of this study are drawn in Section VI.

| II. PROPOSED CONCEPT AND PROTOTYPE

The proposed spherical system consists of an internal rigid frame (IRF) covered by a dielectric elastomer. The IRF, which was fabricated with a rapid prototyping printer [see Fig. 1(a)], served to confer the system a spherical shape and to support the prototype’s weight. The external surface of the prototype was made of a poly(dimethylsiloxane)-based silicone rubber (TC-5005 A/B-C, BJB Enterprises, Inc., Tustin, CA). Following a degassing phase, the polymer was cured in a square Plexiglas mould (30 cm × 30 cm) having 1.2-mm thickness. Once cured, the polymer was peeled from the mould to obtain a flat strip (15 cm × 20 cm), which was subsequently wrapped to form a hollow cylinder as proposed in [12], [18]; the hollow polymeric cylinder had diameter smaller than the IRF diameter. The IRF was inserted inside the polymeric cylinder and its lateral extremities were, subsequently, bent inward and bonded with silicone to completely seal the prototype as shown in Fig. 1(b). The particular shape of the IRF geometrically divided the dielectric elastomer in four sectors. The internal surface of the dielectric

1083-4435/$26.00 © 2011 IEEE

ARTUSI et al.: ELECTROACTIVE ELASTOMERIC ACTUATORS FOR THE IMPLEMENTATION OF A DEFORMABLE SPHERICAL ROVER | 51

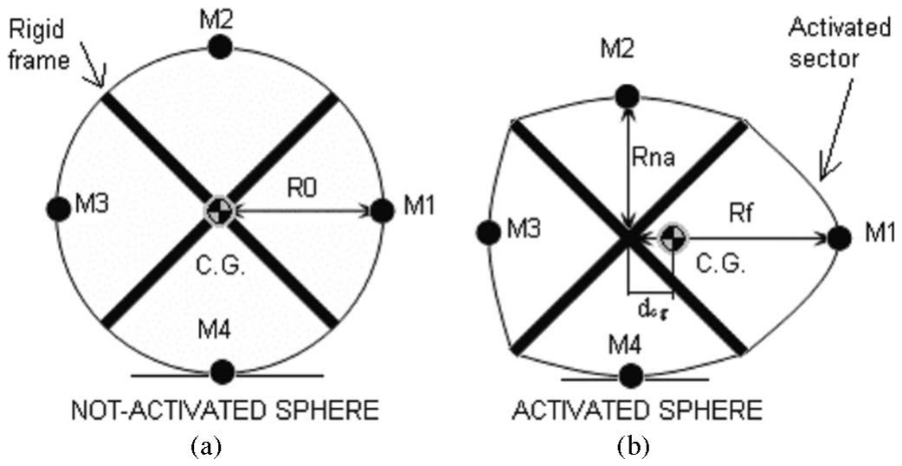
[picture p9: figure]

Fig. 2. | Activation of one DEA sector and consequent displacement of the pro-
totype CG. (a) Inflated but not electrically activated prototype. (b) Deformation caused by the electrical activation of one DEA sector.

elastomer was covered with a deformable electrode, which was, therefore, common to the four sectors of the elastomer. The external surface was instead covered with four different electrodes to enable independent actuation of each sector, called hereafter DEA sectors. The internal and external electrodes were manufactured by spreading carbon powder on the polymer’s surfaces. The prototype was sealed and inflated with air to achieve a spherical shape as schematically represented in Fig. 2(a). Initial conditions of the system, considered for the subsequent analysis, were those in which the prototype had a spherical shape (therefore pressurized) with no electrical field applied. In this configuration, the prototype had internal volume V0 and initial internal pressure p0 ; the system was considered to be isolated and isothermal. In steady-state equilibrium, the pressure p0 exerted by the pressurized air was balanced by the elastic force of the polymer. Under this condition, the spherical prototype had radius R0 [see Fig. 2(a)].
In this study, we hypothesized that the electrical activation of each DEA sector mainly changed the stiffness of that sector. Specifically, it was assumed that when voltage was applied, the stiffness of the activated sector decreased, and therefore, it deformed under the load provided by the pressurized air inside the prototype. This hypothesis, experimentally validated in the following sections of the paper, was used to simplify the dynamic analytical model of the actuator.
The motion of the prototype was generated by the displacement of its CG caused by the activation of one or multiple DEA sectors. Fig. 2 schematically represents the proposed working principle. Each DEA sector is represented by a lumped mass Mi. If one sector is electrically activated, its stiffness decreases and the internal pressure deforms it outward thus increasing its radius (e.g., see M1 and Rf in Fig. 2(b). As the volume changes, the internal pressure decreases. The stiffness of the three inactivated DEA sectors remains, however, unchanged and therefore, due to a drop in internal pressure, their radii decrease until a new equilibrium position is reached (e.g., see M2 –M4 and Rna in Fig. 2). If one sector is activated, the CG of the prototype, therefore, moves toward the electrically activated sector [see the displacement dcg in Fig. 2(b)] and the prototype starts rolling.

III. MECHANICAL BEHAVIOR OF THE DIELECTRIC ELASTOMER

In this section, different models are investigated to represent the mechanical properties of the dielectric elastomer used in this study: TC-5005 A/B-C (BJB Enterprises, Inc., Tustin, CA). Specifically, the Neo–Hookean [13], the Mooney–Rivlin [14], and the Ogden models [15] are investigated. These models are all based on the hypothesis that the elastomer is incompressible; the following equations, therefore, hold true:

V0 = Vf | (1)
l0w0 t0 = lf wf tf | (2)

where l is the length, w is the width, t is the thickness of the sample, and the subscripts 0 and f are, respectively, the initial and final states. By dividing (2) by V0 , the incompressibility condition can be expressed as follows:

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
= a1 · a2 · a3 =1 | (3)

where a1 is the stretch in the direction of the length, a2 is the stretch in the direction of the width, and a3 is the stretch in the direction of the thickness of an elastomeric sample. In the three considered hyperelastic models, the stress σ along the i direction is obtained as the derivative of the strain energy function W with respect to the extension ratio

σi = ai

∂W
∂ai
− ph | (4)

where ph is a component of an assumed external hydrostatic pressure acting on the sample [15].
In the Neo–Hookean model [13], a linear relation between stress and strain is used in replacement of the linear relationship between force and deformation of the Hooke’s model. It is assumed that in a uniaxial tensile test the sample is deformed along one direction, for instance direction 1, and the total stress is a function of the stretch along the same direction, namely,

σ1 = G · a²

1 − G
a1

= G

a²

1 − 1
a1
| (5)

where G is called the shear modulus. The force to deform the sample is the total stress in direction 1 multiplied by the effective cross-section area of the sample [13]

f1 = wf tf G · a−1
1
a²

1 − 1
a1
= w0 t0G
a1 − 1
a²
1
. (6)

The Mooney–Rivlin [14] solid model is a generalization of the Neo–Hookean solid model. It is assumed that in a uniaxial tensile test the total stress along the direction of deformation is

σ1 =

2C1 − ²C2
a1
a²

1 − 1
a1
(7)

where C1 and C2 are two coefficients experimentally determined. The force necessary to deform the sample is

f1 = w0 t0

2C1 − ²C2
a1
a1 − 1
a²
1
. | (8)

52 | IEEE/ASME TRANSACTIONS ON MECHATRONICS, VOL. 16, NO. 1, FEBRUARY 2011

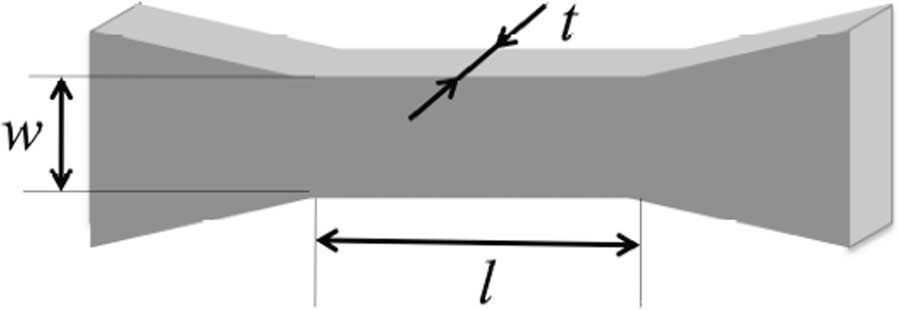
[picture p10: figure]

Fig. 3. | Bone shape of the sample tested.

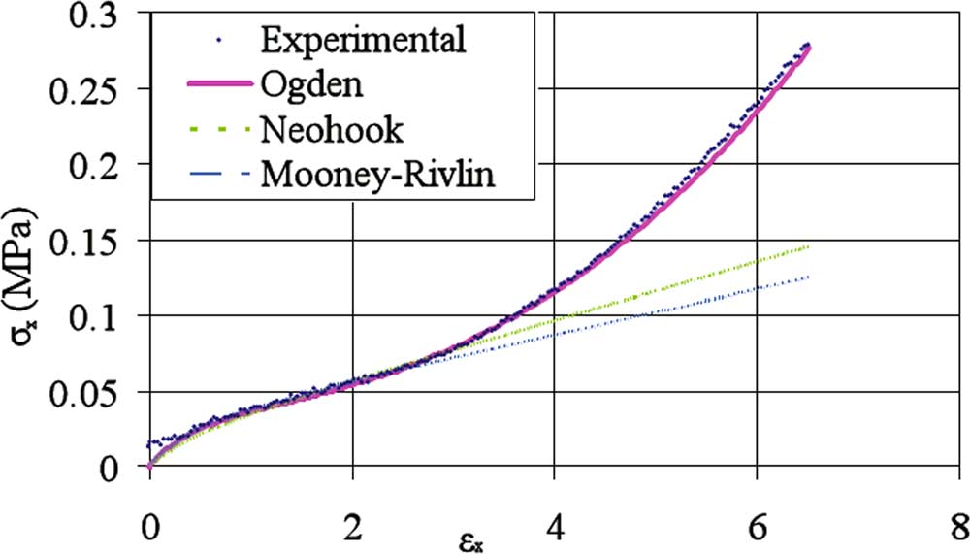
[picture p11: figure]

Fig. 4. | Experimental TC-5005 stress–strain curve fitted by the Ogden,
Mooney–Rivlin, and Neo–Hookean models.
| TABLE I COEFFICIENTS OF HYPERELASTIC MODELS

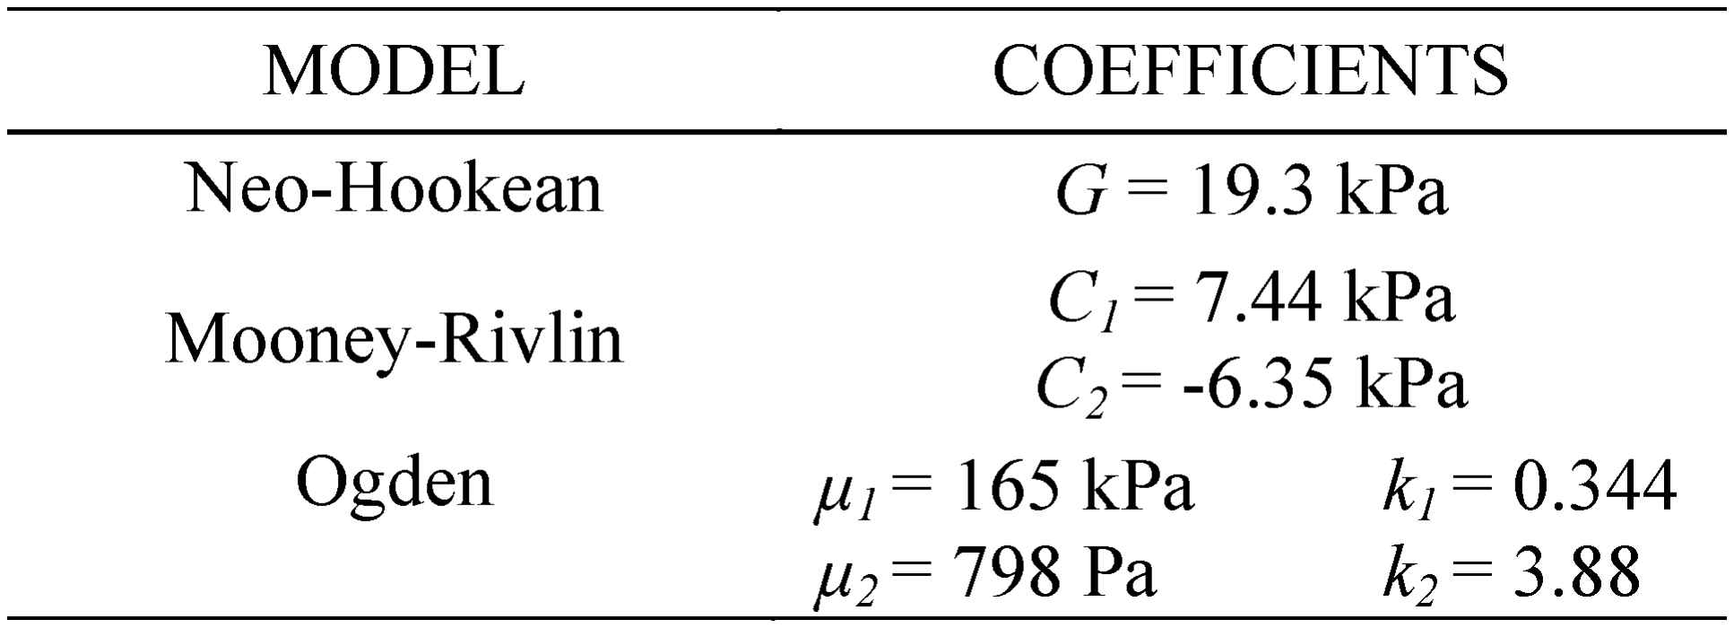
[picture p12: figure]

The Ogden model [15] is based on a different strain energy function compared to the Mooney–Rivlin model; the stress along direction 1 is

σ1 =

n

μn a

kn

1 | − μn a−1/2kn
1 | (9)

where a sum over n is implied and the coefficients μn and kn should be determined experimentally. The force necessary to deform the sample is

f1 = w0 t0

μn a⁽kn −1)

1 | − μn a⁽−1−(1/2)kn )
1
. (10)

The mechanical behavior of TC-5005 was experimentally determined through a tensile test by using an Instron 5848 microtester. The sample tested had a bone shape as represented in 3; the initial dimensions of the sample tested were l0 = 9.1 mm, w0 = 3.04 mm, and t0 = 2.18 mm.
As expected, the tests showed high nonlinearity of the considered elastomer. The experimental data were fitted by using the least-squares method (see Fig. 4) in order to determine the experimental coefficients of the three constitutive models represented by the equations previously introduced. The identified coefficients are summarized in Table I.

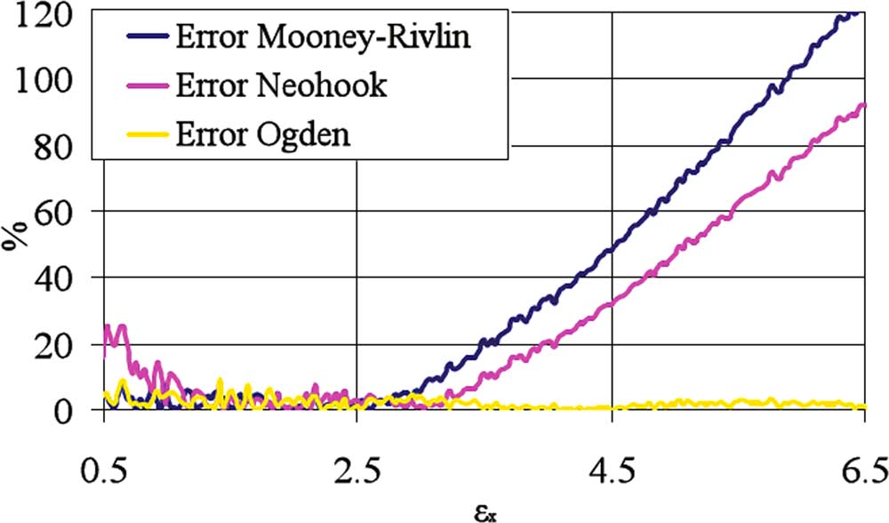
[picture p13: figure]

Fig. 5. | Error between hyperelastic models and experimental data.
| TABLE II MAXIMUM AND AVERAGE ERROR BETWEEN ANALYTICAL AND EXPERIMENTAL DATA

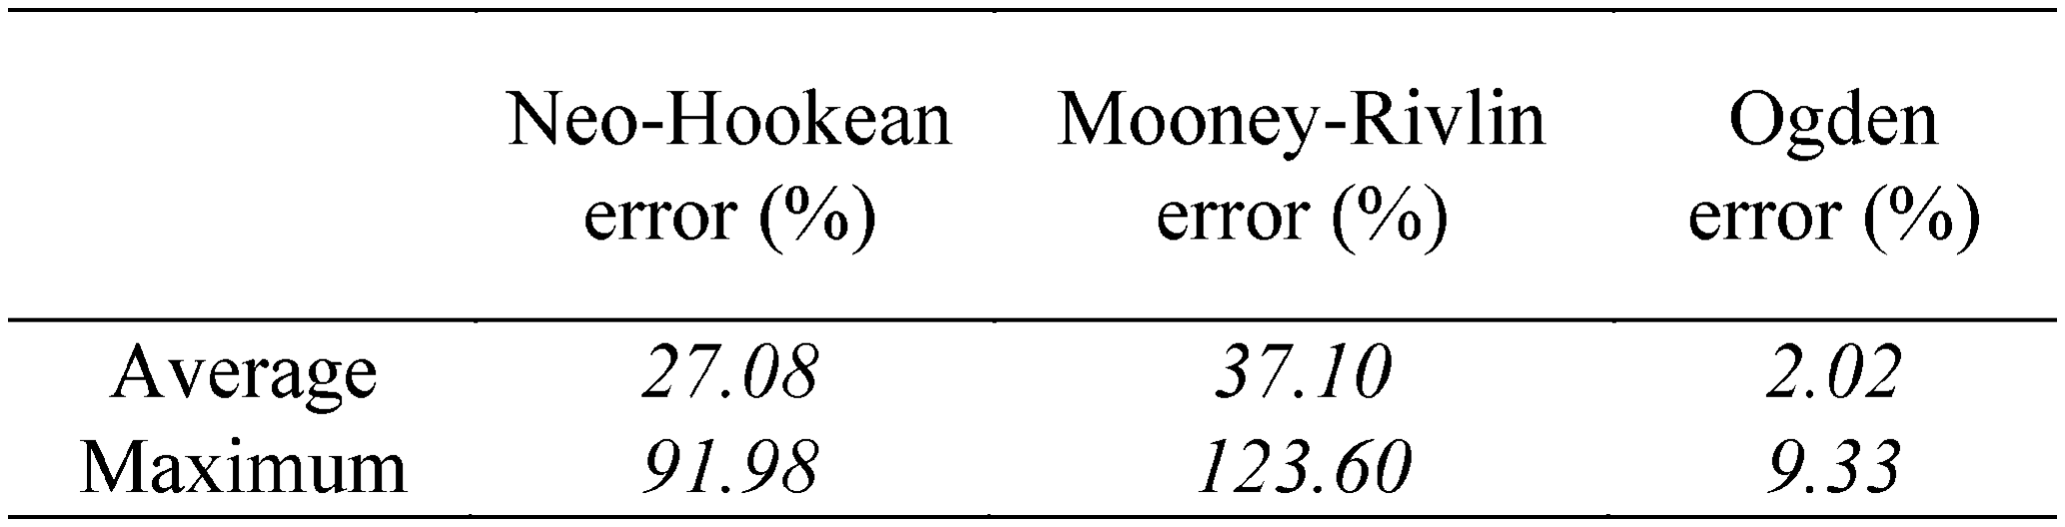
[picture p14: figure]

An error analysis was performed to identify which hyperelastic model would better represent the behavior of the considered elastomer; the error was calculated as follows:

E =

σExp − σhyp

σhyp

× 100 | (11)

where E is the error, σhyp is the stress predicted by the hyperelastic models, and σExp is the measured stress. The obtained results are shown in Fig. 5. The Neo–Hookean model was not very suitable to predict the behavior of TC-5005, as the maximum computed error for the stress was about 92% (see Table II). In addition, this model reported deviation greater than 10% both for strain less than 1 and higher than 3.5 (see Fig. 5. On the other hand, the Mooney–Rivlin model was only suitable to predict relative small strains (0–3 range) as shown in Fig. 5; for strain higher than 3, the error was higher than 10% with a maximum pick of about 124%. The model that better fitted the experimental data was, as expected, the Ogden model. This model, which can be considered a refined version of the Neo–Hookean and Mooney–Rivlin formulations, takes in fact into account also the strain-hardening behavior of the polymer [16]. Table II reports that the Ogden model accurately predicted the experimental data—the maximum error was about 9% and the average error was about 2%. Due to its better performance, the Ogden model was considered in the analytical models presented in the following sections.

IV. DEA SECTORS DYNAMICS

A. Spherical Model

A simplified 3-D lumped parameters model was developed to represent the dynamic behavior of a single DEA sector of the prototype. Each DEA sector was considered rigidly fixed to the

ARTUSI et al.: ELECTROACTIVE ELASTOMERIC ACTUATORS FOR THE IMPLEMENTATION OF A DEFORMABLE SPHERICAL ROVER | 53

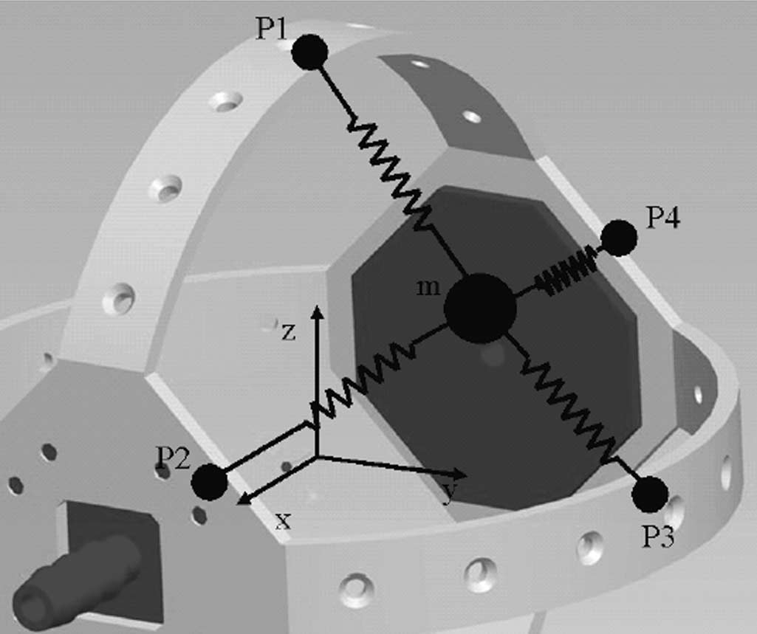
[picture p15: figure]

Fig. 6. | IRF CAD model and lumped-parameter representation of a DEA sector.
| TABLE III DEFINITION OF SYMBOLS USED IN (12)


IRF (as physically implemented in the prototype). The model consisted of a single lumped mass (the mass of the DEA sector) and four symmetrically positioned spring-damper elements connecting the mass to the IRF, as schematically presented in Fig. 6. By using Newton’s law, the following equations were obtained:
⎧
⎪⎪⎪⎪⎪⎪⎪⎪⎪⎨

⎪⎪⎪⎪⎪⎪⎪⎪⎪⎩

mx¨ =(Fki + Fci + F)x

my¨ =(Fki + Fci + F)y

mz¨ =(Fki + Fci + F)z

Fk,i = ki(

(x − xpi)² +(y − ypi)² +(z − zpi)² − l0i)

Fci = ci · vPi
F = π · R²
0 · p
(12)
where, parameters are defined in Table III, subscripts x, y, and z refer to the axes of a Cartesian reference frame (see Fig. 6), and subscript i refers to the specific considered fixed points (for


Fig. 7. Numerical validation of (12). (a)–(c) Displacements along axes x, y, and z of the lumped mass of one elastomer sector.

instance, Fk ,1 is the elastic force between the mass and the fixed point P1).
Equations (12) were validated by using a commercial multibody dynamics software (working model); different initial conditions were considered and the dynamic response of the model was computed. In the scenario considered for validation, the properties of the elastic elements were assumed to be constant and no external forces were applied to the system. Fig. 7 shows displacements of the lumped mass of one sector in the three orthogonal directions x, y, and z for an exemplificative case in which the lumped mass had an initial velocity equal to vx = 10 m/s. It can be seen in Fig. 7 that our model represented by
(12) was consistent with the simulation performed in working model.
The complete analytical model of the spherical prototype was subsequently developed based on (12). The sphere, according to the prototype shown in Fig. 1, had four different sectors and the dynamics of each sector was described by (12). The main additional aspect to be considered was that the deformation of one sector affected the others due to the induced variation of the internal pressure inside the prototype (see Fig. 2). According to Boyle’s law, the pressure inside the prototype changes according to
p0V0 = pf Vf . | (13)

When one sector was activated, the variation of the volume inside the sphere caused a change in pressure, and, as a consequence, also a change in the concentrated force F [see Table III and (12)].
In order to finalize the developed simplified model of the prototype, the effect of the electrical activation of the DEA

54 | IEEE/ASME TRANSACTIONS ON MECHATRONICS, VOL. 16, NO. 1, FEBRUARY 2011

sectors was taken into account, as discussed in the following
section.
B. Model of the Variable DEA Stiffness

The tensile stiffness of TC-5005 is not constant as shown in the experimentally obtained stress–strain curves in Fig. 4. In addition, it should be noted that the DEA tensile stiffness changes when an electrical field is imposed, as a consequence of the induced Maxwell stress [10]–[12]. By using the high-strain model of actuation under load presented in [17], the following relationship was obtained:

S +

εrelε0w0
t0
T²a1 = Fk | | (14)

where S is the external load, εrel is the relative dielectric permittivity, ε0 is the absolute dielectric permittivity, T is the voltage applied, and Fk is the elastic force. The elastic force of the material Fk was computed according to the Ogden hyperelastic model (the experimentally obtained coefficients μn and kn presented in Table I were used). In this study, we hypothesized that the width dimension of the dielectric sector did not change under the imposed loading conditions (namely a2 = 1) as proposed in [16]. The following equation was, therefore, used to model the elastic force:


Fk = w0 t0

n

μn (a⁽kn −1)

1 | − a⁽−1−kn )
1 | ). | (15)

Starting from (14) and applying the definition of tensile stiffness, an analytical model of the hyperelastic stiffness of the material was obtained
ki = S

Δl = Fk − (εrelε0wi/tiT² )a1 lf − l0

| | (16)

where Δl is the elongation of the sample in the direction of the applied external load. Equations (12), (13), and (16) describe the dynamic model of the actuation of the sphere.

C. Parameters Used in Numerical Simulations

The parameters in (12), (13), and (16) were experimentally obtained from the prototype shown in Fig. 1. The stiffness of each spring, according to (16), depended on the dimension of the spring itself, namely on its width (wi), length (li), and thickness (t). The thickness of each DEA sector was related to the thickness of the mould used to fabricate the elastomer while the width and length of each spring depended on the specific IRF geometry. These two latter parameters were computed such that the area defined by wi and li was the same to the area approximately identified by connecting the points P1, A, P2, P3, and B shown in Fig. 8. As the polymer covering the IRF was approximately prestretched about 1.3%, a prestretching coefficient (δ) equal to 1.3 was used to compute the initial relaxed length and width of each spring. The experimentally obtained parameters are summarized in Table IV.
In order to validate the model, different tests were performed. Only quasistatic experiments were carried out—dynamic tests were considered to be not strictly needed in this study, which mainly aimed at presenting the feasibility of the proposed new


Fig. 8. Front view of a sector.

TABLE IV
PARAMETERS USED TO SIMULATE THE ACTUATION OF THE SECTORS


Fig. 9. Side view of the inflated sphere.

concept. Extensive dynamic tests will be performed in the future and reported in a future independent article. Electrical activation and inflating tests are presented in the following sections.

D. Tests

The inflating test consisted on pressurizing with air the prototype until a spherical shape was reached (see Fig. 9). The internal

ARTUSI et al.: ELECTROACTIVE ELASTOMERIC ACTUATORS FOR THE IMPLEMENTATION OF A DEFORMABLE SPHERICAL ROVER | 55

TABLE V
EXPERIMENTAL AND ANALYTICAL VALUES OF TWO RADII OF THE SPHERE WHEN INFLATED WITH A RELATIVE PRESSURE OF 576 Pa


Fig. 10. Inflated prototype with one sector electrically activated (electrical field applied was about 9.3 V/μm).

pressure was measured by a pressure sensor (Omega PX4200– 010GI); the external radius of the sphere was instead identified by postprocessing images (Vision Builder software, National Instruments) of the inflated prototype. A spherical shape was obtained when the internal relative pressure reached about 576 Pa. The deviation of the analytical prediction from the experimental data was computed as

Er =

Rexp − Ranalytical

Ranalytical

× 100 | (17)

where Er is the error between the experimentally measured (Rexp ) and the analytically predicted (Ranalytical) radii. Table V presents results obtained during a test. R1 and R2 are the radii of two DEA sectors as shown in Fig. 9. Discrepancy between R1 and R2 is due, mainly, to the manual manufacturing procedure used to fabricate the prototype. It can be seen that the analytical and experimental results are consistent.
Once inflated, electrical activation tests were performed. Starting from an inflated sphere, the DEA sector #2, corresponding to R2 (see Fig. 9), was electrically activated. As expected, the activated sector moved outward (R2 increased) whereas the other three sectors moved inward (for example R1 decreased). Fig. 10 presents the case in which an electrical field equal to 9.3 V/μm was applied to the DEA sector #2.
Fig. 11 shows both experimental results and analytical predictions for R1 and R2 when different electrical fields were applied. It can be seen that the analytical model takes well into account the variation in Maxwell pressure due to the electrical field, the nonlinear behavior of the dielectric elastomer, and also the variation of the internal pressure due to the variation of the volume of the prototype, which all affect the variation of the radii. Table VI confirms this statement: the maximum recorded Er was less than 3%, which is very low when taking into account the limitations of the manufactured prototype.


Fig. 11. Relative variations of R1 and R2 recorded when the DEA sector #2 was electrically activated.

| TABLE VI
EXPERIMENTAL AND ANALYTICAL ACTIVE (R2 ) AND INACTIVE (R1 )
| RADII OF THE SPHERE


TABLE VII
DEFINITION OF THE PARAMETERS USED IN (18)


V. SPHERE ROTATION

The prototype had a spherical shape and its revolute motion was generated by the displacement of the CG caused by the activation of one or multiple DEA sectors. The following simplified single lumped mass model of the sphere was used to predict the rotation of the prototype:

Is × ¨θ =(ms × g × dcg ) × sin θ | (18)

where Is is the inertia of the prototype, which was assumed to be constant and was computed starting from the CAD model of the prototype, θ is the angle describing the rotation of the sphere, ms is the mass of the sphere, g is the gravitational acceleration, and dcg is the prototype’s CG displacement caused by the activation of the DEA sectors; sin(θ) was used to take into consideration the torque variations caused by the rotation of the prototype. It should be noted that the deformations of the DEA sectors were computed according to (12), (13), and (16). The parameters used in the analytical model are reported in Table VII. Fig. 12 shows different snapshots of the rolling prototype.

56 | IEEE/ASME TRANSACTIONS ON MECHATRONICS, VOL. 16, NO. 1, FEBRUARY 2011


Fig. 12. | Snapshots during a rotation test of the prototype.


Fig. 13. | Comparison between experimental and analytical data for the man-
ufactured prototype. (a) Initial angle was 68.3◦. (b) Initial angle was 80.5◦.
(c) Initial angle was 89.6◦.

Fig. 13 presents results about three tests in which the prototype had three different initial positions [the initial position is identified by the rotation angle θ shown in Fig. 12 (a)]. In the three tests reported in Fig. 13, a single DEA sector was activated. For each test, a video was recorded and its frames analyzed to determine the prototype’s performance. Fig. 13 shows that the analytical prediction was consistent with the experimental results. Table VIII reports results of the error analysis that was performed. It can be seen that the maximum deviation of the analytical prediction from the experimental results was, on average, about 8%, which is relatively low considering the imperfections that the manually fabricated prototype had.

TABLE VIII
MAXIMUM AND AVERAGE ERROR BETWEEN THE ANALYTICAL AND EXPERIMENTAL DATA IN FIG. 13


Fig. 13 allows determining the potential performance of the prototype. Specifically, a maximum angular velocity of 0.8 rad/s was reached, corresponding to a linear velocity of 43 mm/s for our prototype, which had an external radius equal to 54 mm. The recorded maximum angular acceleration was 0.42 rad/s² (22 mm/s² linear velocity for our prototype).

VI. CONCLUSION

This paper presented and validated a new conceptual design for future lightweight rolling rovers potentially suitable for exploration and scouting missions. The proposed prototype consisted of an IRF and an external deformable surface made of DEA sectors. Different analytical models were developed to investigate the behavior of the DEAs, the dynamics of each DEA sector, and the rolling performance of the prototype. Specifically, a comparison among different hyperelastic models was performed to represent the behavior of the used dielectric elastomer; it was shown that the Ogden model could describe the stress–strain curve with a maximum error of 9%. Experimental tests were performed to validate a 3-D model developed to predict radial displacements of the sectors of the prototype; the maximum deviation between analytical and experimental results was 3%. Experimental tests were also performed to identify the rolling performance of the prototype; the proposed analytical model was able to describe the rotation angle of the prototype with a maximum error of 11.8%. The maximum angular acceleration of the developed prototype was 0.42 rad/s² . The fabricated prototype could potentially fulfill stringent requirements concerning mass and volume; indeed, the whole weight of the prototype was only 75 g and its volume, once inflated, was 660 cm³—the prototype could potentially have a total folded volume (in the case of foldable internal frame) of about 30 cm³ .

ACKNOWLEDGMENT

The author would like to thank M. Soleimani and X. Jiang from the MENRVA Research Group for their useful suggestions and comments.

REFERENCES

[1] A. Behar, J. Jones, and F. Carsey, “NASA/JPL Tumbleweed Polar Rover,” presented at the IEEE Aerospace Conf., Big Sky, MT, 2004.
[2] R. Mukherjee, M. A. Minor, and J. T. Pukrushpan, “Simple motion planning strategies for spherobot: A spherical mobile robot,” presented in the 38th IEEE International Conf. Decision and Control, Phoenix, AZ, 1999.
[3] A. H. Javadi A. and P. Mojabi, “Introducing glory: A novel strategy for an omnidirectional spherical rolling robot,” J. Dynam. Syst. Meas, Control, vol. 126, no. 3, p. 678, 2004.

ARTUSI et al.: ELECTROACTIVE ELASTOMERIC ACTUATORS FOR THE IMPLEMENTATION OF A DEFORMABLE SPHERICAL ROVER | 57
[4] J. Suomela and T. Ylikorpi, Ball-Shaped Robots: An Historical Overview
and Recent Developments at TKK(Springer Tracts in Advanced Robotics), vol. 25. Berlin, Germany: Springer, 2006, pp. 343–354.
[5] C. Menon, M. Ayre, and A. Ellery, “Biomimetics: A new approach for space systems design,” ESA Bull. 125, pp. 20–26, 2006.
[6] G. Hajos, J. Jones, A. Behar, and M. Dodd, “An overview of winddriven rovers for planetary exploration,” presented at the 43rd Amer. Inst. of Aeronautics and Astronautics (AIAA) Aerospace Sci. Meet. Exhibit, Reno, NV, 2005.
[7] S. Yuuta and H. Shinichi, Crawling and Jumping of Deformable Soft Robot (Springer Tracts in Advanced Robotics), vol. 21. Berlin, Germany: Springer, 2006, pp. 281–291.
[8] Y. Bar-Cohen, Ed., Electroactive Polymer (EAP) Actuators as Artificial Muscles. Reality, Potential, and Challenges, 2nd ed. Bellingham, WA: SPIE, 2004.
[9] J. D. Madden, N. Vandesteeg, P. G. Madden, A. Takshi, R. Zimet, P. A. Anquetil, S. R. Lafontaine, P. A. Wierenga, and I. W. Hunter, “Artificial muscle technology: Physical principles and naval prospects,” IEEE J. Ocean. Eng., vol. 29, no. 3, pp. 706–728, Jul. 2004.
[10] R. E. Pelrine, R. D. Kornbluh, and J. P. Joseph, “Electrostriction of polymer dielectrics with compliant electrodes as a means of actuation,” Sens. Actuators, vol. 64, no. 1, pp. 77–85, 1998.
[11] R. Perline, R. Kohrnbluh, Q. Pei, and J. Joseph, “High-speed electrically actuated elastomers with strain greater than 100%,” Science, vol. 287, pp. 836–839, 2000.
[12] F. Carpi, C. Menon, and D. De Rossi, “Electroactive elastomeric actuator for all-polymer linear peristaltic pumps,” IEEE/ASME Trans. Mechatronics, vol. 15, no. 3, pp. 460–470, Sep. 2009.
[13] C. W. Macosko, Rheology: Principles, Measurements, and Applications. New York: VCH, 1994.
[14] M. Mooney, “A theory of large elastic deformation,” J. Appl. Phys., vol. 11, pp. 582–592, 1940.
[15] R. W. Ogden, “Large deformation isotropic elasticity—On the correlation of theory and experiment for incompressible rubberlike solids,” Proc. R. Soc. Lond. A, vol. 326, pp. 565–584, 1972.
[16] G. Kofod and P. Sommer-Larsen, “Silicone dielectric elastomer actuators: Finite-elasticity model of actuation,” Sens. Actuators A, Phys., vol. 122, no. 2, pp. 273–283, 2005.
[17] L. Patrick, K. Gabor, and M. Wissler, “Characterization of dielectric elastomer actuators based on hyperelastic film model,” Smart Mater. Struct., vol. 16, no. 2, pp. 477–486, 2007.
[18] M. Soleimani and C. Menon, “Preliminary investigation of a balloonshape actuator based on electroactive elastomers,” Smart Mater. Struct., vol. 19, no. 4, p. 6, 2010.
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

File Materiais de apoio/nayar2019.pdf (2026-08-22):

Research Article

# Design optimization of a lightweight rocker–bogie rover for ocean worlds applications

### Hari Nayar¹ , Junggon Kim¹

### , Brendan Chamberlain-Simon¹

,

### Kalind Carpenter¹

### , Michael Hans¹

### , Anna Boettcher¹

,

### Gareth Meirion-Griffith¹

### , Brian Wilcox¹ and Brian Bittner²

Abstract
Relatively recent discoveries have shown that large quantities of water can be found on moons of some of the planets among the gas giants in our solar system. Robotic mobility systems can study the varied geology and origins of these bodies if they are able to navigate the complex terrains of ocean worlds. The topographical features of ocean worlds present a unique combination of challenges for mobility. These include cryogenic ice, penitentes, salt evaporites, chaotic regions, and regolith with uncertain shear and sinkage properties. Uncertainty in both terrain properties and geometry motivates design of a platform that is mobile within a large range of obstacle geometries and terrain properties. This article reports on a research effort to study the requirements and numerically optimize the kinematic parameters of the rover to satisfy these goals. The platforms selected in the process were further verified via simulation. A simulation and analysis of grousers generated suitable designs for interaction with similar ledges and rough terrain. From this analysis, a prototype was developed and tested to meet the wide range of topography and terramechanics conditions expected on these bodies.

Keywords
Planetary surface exploration, ocean worlds, rocker–bogie rover, wheeled mobility, mobility optimization

Date received: 30 July 2019; accepted: 23 September 2019

Topic: Mobile Robots and Multi-Robot Systems
Topic Editor: Nak-Young Chong
Associate Editor: Chang-bae Moon

### Introduction

Discovery of large quantities of water among bodies in our outer solar system has boosted interest in future space missions to these bodies.¹,2 The ingredients for life,³ (1) liquid water, (2) rocky cores in contact with the oceans to provide salts and other chemicals needed for life, (3) energy fed into the oceans either from hydrothermal sources in the mantle or tidal activity, and (4) stable environments that could promote production of complex molecules and potentially life, are all likely on Europa, a moon of Jupiter, and Enceladus, a moon of Saturn.
One of the principle goals for missions to these ocean world bodies is to gather astrobiological data. Finding life or signs of life beyond earth would be an extraordinary discovery. More easily attainable goals of understanding the geology and origins of ocean worlds are also of a significant science value.⁴ Evidence from previous missions and remote sensing from earth shows that Europa and

1
Robotics and Mobility Systems, California Institute of Technology, NASA Jet Propulsion Laboratory, Pasadena, USA
2Robotics Institute, University of Michigan, Ann Arbor, USA

Corresponding author:
Hari Nayar, Robotics and Mobility Systems, California Institute of Technology, NASA Jet Propulsion Laboratory, Pasadena, CA 91101, USA. Email: hdnayar@jpl.nasa.gov

International Journal of Advanced Robotic Systems
November-December 2019: 1–20 ª The Author(s) 2019
DOI: 10.1177/1729881419885696 (https://doi.org/10.1177/1729881419885696) journals.sagepub.com/home/arx

Creative Commons CC BY: This article is distributed under the terms of the Creative Commons Attribution 4.0 License (http://www.creativecommons.org/licenses/by/4.0/) which permits any use, reproduction and distribution of the work without further permission provided the original work is attributed as specified on the SAGE and Open Access pages (https://us.sagepub.com/en-us/nam/open-access-at-sage). (https://us.sagepub.com/en-us/nam/open-access-at-sage)

Enceladus both have varied and active or recently active surface geologic processes.⁵ A mission to explore a large range of terrain types would provide an understanding of the origins and history of the body.
A study was conducted to generate robotic surface mobility concepts to cover a large range of the surface of ocean world bodies. The requirements for the concepts were to (1) be able to cover a distance of at least 10 km over a range of terrain types to be found on ocean worlds,
(2) handle the range of material types from hard ice rock to noncohesive granular ice, and (3) operate in the environmental conditions of cryogenic temperatures and vacuum and meet mission constraints of power, mass, and volume. The 10 km drive goal was derived from a study of images of Europa, for example, as shown in Figure 1, showing a 35 km by 50 km patch of varied terrain, where it was determined that, with an appropriately selected landing site, it would be possible to visit at least three different terrain types within a 10-km travel distance. Among the concepts generated was a vehicle that drives over the surface. Earlier results from this work were reported in Nayar et al.⁶ This article provides more details and includes an analysis of wheel grousers and experimental and field results from tests conducted on the prototype vehicle.
The contributions of this article are multifold. First, the known geological features of ocean worlds are organized and presented as potential mobility hazards. This information is immediately useful for the design and development of systems to be sent to regions with similar mechanical and topographical properties. Next, the motivation for the design is provided. The design kinematics are optimized via simulation using metrics that prioritize the extreme nature of ocean world terrains. A subsequent simulationbased analysis identified ranges of grouser designs that interact with ledges and identified parameters for the extreme geometric obstacles. Experimental validation of a prototype confirms the viability of the platform optimized through analysis and simulation.
The article begins with a survey of terrain classes on Europa and their relation to mobility (second section).

These considerations drive three design requirements for the mobile platform (third section). The subsequent kinematic optimization framework (fourth section) is evaluated via simulation (fifth section). Given platform kinematics, a study of grousers renders a design space of suitable wheels (sixth section). A prototype was built using the recommended design parameters from the analysis and simulation. The performance of the prototype was compared to the predicted performance (seventh section). The article concludes with a summary (eighth section). The overall development process pursued in this study is illustrated in Figure 2.

### Environmental considerations

Water is an essential ingredient for life. Recent observations in the outer solar system have revealed that many satellites of the outer planets contain large quantities of water. These bodies, along with our earth, have been called ocean worlds. Europa and Enceladus are of particular interest and prime targets because of the confirmed presence of liquid water below their icy crusts. Liquid water also implies that they have a subsurface energy source, another essential ingredient for life. In addition to the astrobiology goal, surface exploration has science value for studies of ice geology and planetary origins. The environmental conditions for mobility on these bodies are challenging. The surface temperature on Europa is between 76 K and 130 K,⁷ while on Enceladus, it is between 65 K and 140 K.⁸ Europa poses the additional burden of designing for high radiation exposure at its surface.⁹ The greatest challenge is possibly the surface topography and mechanical properties of the terrain. The ice crusts covering Europa and Enceladus are primarily composed of water many kilometers thick. The Cassini and Galileo missions have, respectively, shown distinct surface features that include double ridges, bands, chaos, and lenticulae. Surface mobility will be challenging over the varied and rugged terrain. Furthermore, plume vents have been detected on Enceladus by Cassini¹ and more recently on Europa by Hubble.¹⁰ Deposition of condensate from the plumes on the surface in proximity to the vents will probably be fine-grained cryogenic ice regolith, posing another challenge for surface mobility.
This study focuses on the vehicle design to address the topography and terramechanics. For the deployment on an ocean world body, additional measures will have to be taken. For example, to meet the constraints of temperature extremes, designs using heaters to maintain temperatures within the operating ranges of component systems or using components that can withstand the extreme low temperature or a combination are possible. A myriad of other precautions, for example, shielding against radiation on Europa, will be needed for the cruise to, descent, landing and operation on the surface.
The gravitational field at the surface on Europa is 1.3 m/s² (slightly lower than our moon’s gravitational

Figure 1. Mosaic of Conamara Chaos region on Europa. Image credit: NASA/JPL/U Arizona.

2 | International Journal of Advanced Robotic Systems


strength) while on Enceladus it is 0.11 m/s²
. This large
difference will require significantly different strategies for dynamic driving over the surface. It may even be possible to take advantage of the very low gravity on Enceladus and use modes of traverse that liftoff over the surface. The quasi-static analysis for vehicle design, however, is still applicable as the vehicle would be driven in slow and precise motions on the surface during science operations.
The design of vehicles to traverse over these bodies requires knowledge about the topography and mechanical properties of the surface. These are both strategies being pursued in the development of future surface mission systems. The highest resolution surface imagery we currently have are from Galileo (orbiting Jupiter) and Cassini (orbiting Saturn) with pixel sizes of 6 m and 20 m, respectively. These resolutions are significantly larger than likely vehicle sizes and do not provide adequate information of the surface at the vehicle scale. Earth analog studies have identified several pathological cases that need to be considered for robotic mobility. They include cryogenic ice, penitentes, regolith, salt evaporites, and chaos terrain, as illustrated in Figure 3. These are described in the following subsections. To better understand the mechanical properties of material on the surface, samples were tested under cryogenic and vacuum conditions. The results are also reported in a following subsection.

### Cryogenic ice

The near-surface material on Europa and Enceladus is primarily composed of cryogenic ice (Figure 3(a)). Unlike naturally occurring ice on the surface of the earth, cryogenic ice is exceptionally hard, with a compressive strength measured at 110–120 MPa in laboratory tests.¹¹ It can take on many morphologies (Figure 3(b), (c), and (e)) as described in the following subsections.

### Penitentes

At low surface pressures (as is the case on Europa and Enceladus), and incident solar illumination close to perpendicular (at equatorial latitudes), near-vertical ice spikes up to 1–5 m in length, called penitentes, form naturally (Figure 3(b)) due to solar concentration and ice sublimation in troughs.¹² On earth, these are observed in the Andes. Mobility over penitentes is difficult to conceive and will probably require a specialized mobility system to handle their unique morphology.

### Cryogenic ice regolith

The presence of an ice regolith and measurement of the characteristics of the top layer of ice have been derived from remote sensing. Estimates of ice particle sizes in the range of twenty to several hundreds of micrometers in size are predicted from photometry in the visible spectrum range of 380–770 nm. At these wavelengths, light penetrates only the top tens of micrometers¹³ of the surface, but these observations may imply significant depths of material with these properties. Surface compaction and void ratios in the surface material have been measured at 25% on the leading side of Europa and 75% on the trailing side.¹⁴ These are consistent with expected values due to the variation of surface exposure to radiation on the leading and trailing sides. In addition, the upper most layer of the surface is likely formed of <1.5 mm particles with void spaces of up to 95% or more.¹³,15 RADAR measurements¹⁶ show that both Europa and Enceladus are bright to backscatter at a wide range of wavelengths implying likelihood of a very well-graded regolith that may be many meters deep.

### Salt evaporites

Remote sensing imagery showing brown, orange, or yellow surface discolorations on the surface of Europa is believed to indicate salt evaporites (Figure 3(d)) composed of

Figure 2. The steps in the development process taken in this study.

Figure 3. From left to right: (a) cryogenic ice, (b) penitentes, (c) regolith, (d) salt evaporites, and (e) chaos.

Nayar et al. | 3


non-ice chemical species deposited on the surface either from subsurface materials or from material deposited from other bodies, for example, volcanism on Io. These materials concentrate and form salt crystals as the ice sublimates. On earth, they are found in dry lake basins (e.g. Devil’s Golf Course) where they are formed through a very similar process. The crystalline material can have a wide range of mechanical properties from weak and brittle to hard. Their structures are potentially challenging for surface mobility due to the resulting rugged topology.

### Chaos

There are chaos (Figure 3(e)) regions visible from remote imagery, for example, at Thera Macula on Europa, that display a significant fractured material that is potentially the result of tectonic activity and periodic tidal forces as Europa orbits Jupiter. With cryogenic ice regolith (described in subsection “Cryogenic ice regolith”) layered on these chaos regions, the combination of rugged topography and loose granular material will pose significant challenges to mobility and navigation and present a high risk for entrapment.

### Ground material characterization

One of the principal goals of this study was to evaluate the performance of a mobility architecture that has been used on prior planetary exploration missions. Direct measurement of the geotechnical properties of the material on the surface of ocean world bodies is not possible. However, it is possible to physically simulate the material under the expected environmental conditions on these bodies and perform experiments to determine its properties. For wheeled mobility on the surface, the properties of interest are the material shear strength according to the Mohr–Coulomb failure criterion and the bearing strength under normal load. A cryogenic vacuum chamber, capable of maintaining a regolith temperature of 100 K, inside a near-vacuum of 600–1200 Pa as shown in Figure 4, was used to investigate the properties of a granular, cryogenic ice regolith. Measures of these properties enable the estimation of sinkage (a function of bearing capacity) and the thrust (a function of shear strength) that a vehicle may achieve on a granular media. Two particle sizes (10 mm to 2 mm) and two manufacturing processes were used to prepare the ice grain particles for the experiments. The first process, to simulate angular ice grains formed during the fracturing of tectonic processes, was mechanically fractured and sieved directly into a liquid nitrogen bath. The second process, to simulate amorphous particles likely found beside an Enceladus plume, involved liquid water droplets dispersed from an atomizing nozzle directly into a liquid nitrogen bath. The samples did not have any exposure to ambient conditions during these processes to prevent vapor deposition and sintering that would result in interparticle cohesion. Preliminary results from the direct shear tests are shown in Figure 5. The results from the cryogenic vacuum tests represent one end of the range of terramechanics properties for soils on ocean world bodies where the material is assumed to be composed of loose granular material. The other extreme is for the material to have the properties of hard fused rock.
The significant challenge in developing robotic systems to operate on the extreme planetary surface terrains of Europa and Enceladus is the lack of detailed knowledge of the topography on the scale of the vehicle size and the terramechanics of the material on the surface. That information will remain inaccessible until measurements can be made by future surface missions.
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

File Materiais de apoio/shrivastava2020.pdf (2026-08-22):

Shrivastava et al., Sci. Robot. 5, eaba3499 (2020) 13 May 2020

### SCIENCE ROBOTICS | RESEARCH ARTICLE

### 1 of 10

SPACE ROBOTS

# Material remodeling and unconventional gaits facilitate locomotion of a robophysical rover over granular terrain

Siddharth Shrivastava¹

*, Andras Karsai²

*†

, Yasemin Ozkan Aydin²

, Ross Pettinger³
,
William Bluethmann⁴

, Robert O. Ambrose⁴

, Daniel I. Goldman²†
Autonomous robots and vehicles must occasionally recover from locomotion failure in loosely consolidated granular terrain. Recent mobility challenges led NASA Johnson Space Center to develop a prototype robotic lunar rover Resource Prospector 15 (RP15) capable of wheeled, legged, and crawling behavior. To systematically understand the terradynamic performance of such a device, we developed a scaled-down rover robot and studied its locomotion on slopes of dry and wet granular media. Addition of a cyclic-legged gait to the robot’s wheel spinning action changes the robot dynamics from that of a wheeled vehicle to a locomotor paddling through frictional fluid. Granular drag force measurements and modified resistive force theory facilitate modeling of such dynamics. A peculiar gait strategy that agitates and cyclically reflows grains under the robot allows it to “swim” up loosely consolidated hills. Whereas substrate disturbance typically hinders locomotion in granular media, the multimode design of RP15 and a diversity of possible gaits facilitate formation of self-organized localized frictional fluids that enable effective robust transport.
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

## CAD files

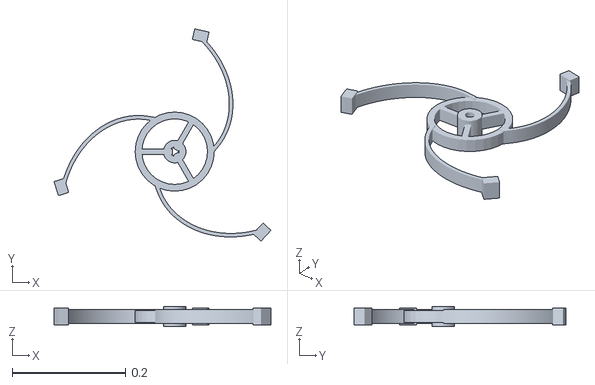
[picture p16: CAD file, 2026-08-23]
ros2_ws/src/rover_frugal_description/meshes/roda_raios_curvos.stl
0.384 x 0.375 x 0.036

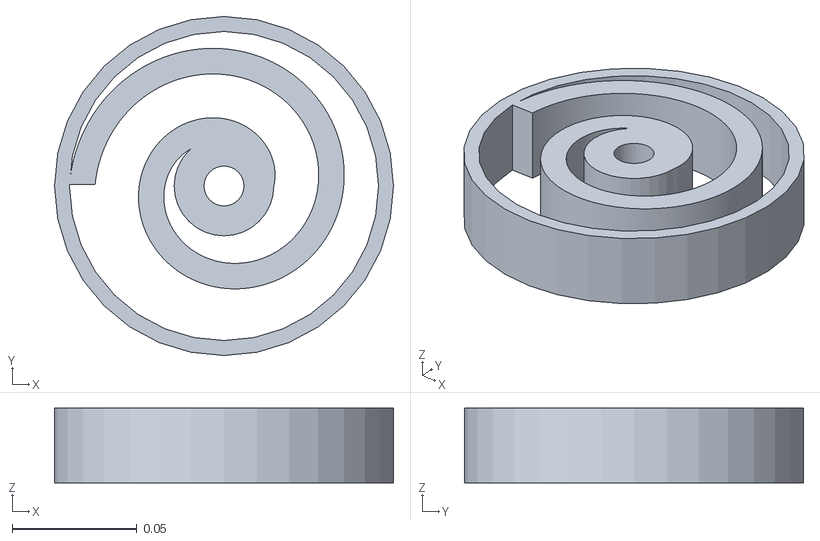
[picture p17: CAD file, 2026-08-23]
ros2_ws/src/rover_frugal_description/meshes/espiral_csts.stl
0.136 x 0.136 x 0.03

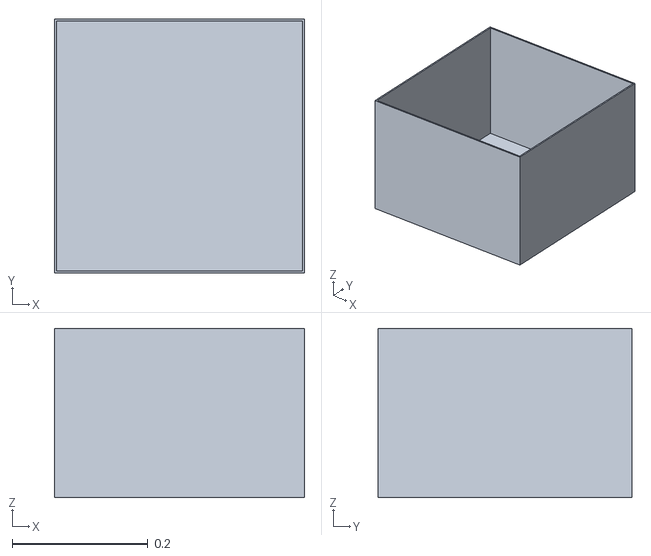
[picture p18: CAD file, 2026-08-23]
ros2_ws/src/rover_frugal_description/meshes/caixa_organizadora.stl
0.369 x 0.375 x 0.25

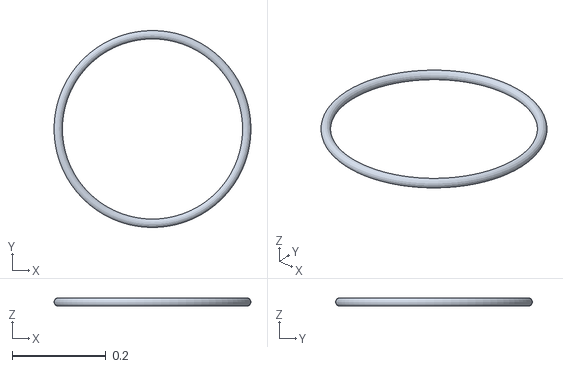
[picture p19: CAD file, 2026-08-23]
ros2_ws/src/rover_frugal_description/meshes/aro_elastico.stl
0.42 x 0.42 x 0.0175

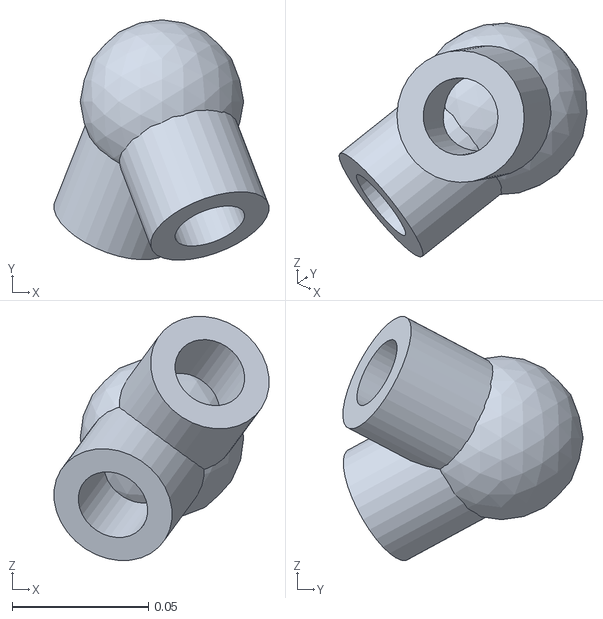
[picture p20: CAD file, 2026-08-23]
ros2_ws/src/rover_frugal_description/meshes/junta_vertice.stl
0.0789 x 0.0882 x 0.0896

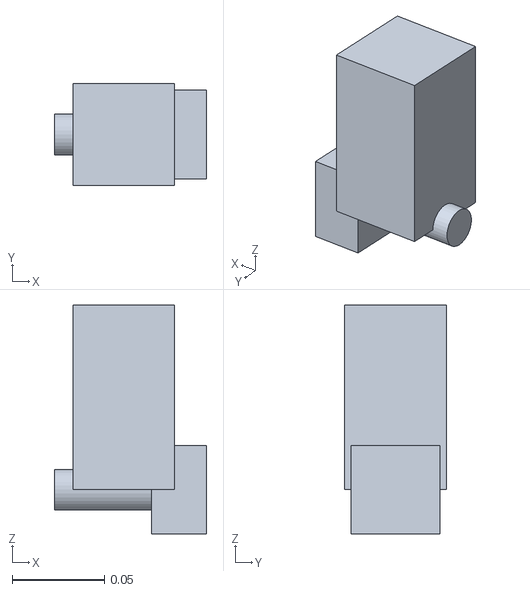
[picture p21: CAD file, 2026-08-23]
ros2_ws/src/rover_frugal_description/meshes/manga_4ws.stl
0.0825 x 0.055 x 0.124

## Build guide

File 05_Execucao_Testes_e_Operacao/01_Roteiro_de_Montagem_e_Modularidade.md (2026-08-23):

# 01. Roteiro Prático de Montagem, Mecanismos e Modularidade
## Guia Passo a Passo com Juntas Split-Clamp e Presilhas Toggle (Sclater & Chironis, 2001)

> [!IMPORTANT]
> **Revisão R2 — atualizado**
> Os comprimentos de corte de tubo (350/400 mm) não fecham com a geometria vigente e foram substituídos por tabela derivada dos parâmetros mestres. O curso da suspensão passou de 35 para **90 mm**, o que muda o projeto da manga.
>
> Parâmetros vigentes: [`00_Especificacao_Mestre/00_Parametros_Mestres.md`](../00_Especificacao_Mestre/00_Parametros_Mestres.md) ·
> Achados: [`02_Auditoria_Tecnica.md`](../00_Especificacao_Mestre/02_Auditoria_Tecnica.md)

---

---

## 1. Visão Geral do Processo Construtivo

A montagem do rover é dividida em módulos mecânicos desacoplados, permitindo que a estrutura tubular de PVC, os conjuntos de roda 4WS/4WD e a caixa de carga sejam montados de forma modular e independente:

```mermaid
graph TD
    A[Corte dos Tubos de PVC de Água Fria] --> D[Montagem dos Braços em V]
    B[Impressão 3D das Juntas Split-Clamp e Rodas] --> D
    C[Montagem das Mangas 4WS + Motores 4WD] --> D
    D --> E[Instalação da Suspensão em Elásticos + Batentes]
    E --> F[Fixação Rápida por Presilhas Toggle na Caixa]
    G[Integração do Chicote Elétrico Plug-and-Play] --> F
    F --> H[Testes de Continuidade e Pré-Voo]
```

---

## 2. Passo a Passo Detalhado de Montagem

### Etapa 1: Corte e Preparação dos Tubos de PVC

> **Lista de corte derivada, não digitada.** Os comprimentos abaixo são calculados
> a partir das posições de roda, da altura de fixação pendular e do curso da
> suspensão por `simulador_python/estrutura.py`. Se a geometria mudar no arquivo
> mestre, regenere com `python3 -m simulador_python.estrutura`.

| Qtd. | Peça | Comprimento de corte | Ângulo | Trecho |
| :---: | :--- | ---: | ---: | :--- |
| 4x | Haste superior (ascendente) | **185 mm** | +56.9° | abraçadeira da caixa → vértice do V |
| 4x | Haste inferior (descendente) | **288 mm** | +56.1° | vértice do V → manga de esterçamento 4WS |

O comprimento de corte já inclui **30 mm de encaixe dentro de cada junta
split-clamp** em ambas as extremidades. Tubo de PVC predial de água fria,
diâmetro nominal 25 mm.

**Envelope resultante do veículo:** 1110 mm (comprimento) ×
664 mm (largura) × 470 mm (altura).
Passa em porta de 800 mm com **136 mm de folga**;
raio de giro no próprio eixo: 667 mm.

1. Cortar com serra de arco e caixa de esquadria, conferindo cada peça com
   paquímetro (tolerância ±1 mm — erro de comprimento vira desalinhamento de roda).
2. Lixar as extremidades com lixa d'água grão 220 para remover rebarbas.
3. **Marcar com caneta permanente** a linha de inserção em cada extremidade: se o
   tubo escorregar dentro da junta em operação (modo de falha F-40 da FMEA), a
   marca denuncia visualmente antes que a geometria se perca.

### Etapa 2: Montagem das Mangas de Eixo 4WS e Motores 4WD
1. Inserir sob leve pressão os rolamentos de esferas 608ZZ nos alojamentos das mangas de eixo 3D.
2. Fixar o servomotor de esterçamento digital de 25 kgf·cm no suporte da manga e conectar o braço mecânico (*servo horn*) metálico ao eixo vertical da manga.
3. Parafusar o motorredutor DC de tração 12V 4WD na flange inferior da manga de eixo.
4. Acoplar a roda *curved spokes* impressa em PETG ao eixo do motorredutor utilizando acoplador sextavado de latão com parafuso prisioneiro (*grub screw*).

### Etapa 3: Instalação da Suspensão Elástica com Batente de Fim-de-Curso (Sclater & Chironis, 2001)
1. Conectar a manga de eixo à haste de PVC inferior através do pino de articulação em aço inoxidável M4.
2. Posicionar os carretéis de ancoragem impressos em 3D.
3. Instalar o feixe de elásticos de escritório comuns (**8 elásticos nº 18 por
   perna**, sob pré-alongamento de aproximadamente $20\%$), totalizando
   $\approx 1000\text{ N/m}$ por roda.
4. Verificar que o curso vertical livre da manga é de **90 mm** — e não 35 mm como
   na revisão anterior. Esse curso é dimensionado pela energia da queda de cubo na
   escada (89 mm de queda, 7,6 J a dissipar); com 35 mm a suspensão bate no
   batente a cada transferência de raio e a carga recebe 4,2 g em vez de 0,8 g.
5. Verificar se o **batente de fim-de-curso** (parafuso M4 + porca, **metálico**,
   não impresso — ver F-14 na FMEA) limita a sobre-extensão, protegendo o feixe.
6. Medir o **afundamento estático** com o veículo montado e carregado: deve ficar
   em torno de 22 mm (24% do curso). Fora da faixa de 18 a 28 mm, ajustar o número
   de elásticos por perna.

### Etapa 4: Montagem do Vértice Superior em "V Invertido" com Juntas *Split-Clamp*
1. Inserir a haste superior e a haste inferior na junta angular do vértice 3D.
2. Apertar os parafusos tangenciais Allen M4 com porcas autotravantes (*parlock*).
3. **Torque de Aperto Recomendado**: Aplicar torque de $1,8 \text{ a } 2,2 \text{ N}\cdot\text{m}$ (suficiente para travar o PVC por atrito de $360^\circ$ sem esmagar a parede do tubo).

### Etapa 5: Acoplamento na Caixa por Presilhas *Toggle Over-Center*
1. Posicionar os 4 suportes de fixação rápida nas quatro quinas do **terço superior** da caixa organizadora plástica.
2. Travar as **4 presilhas articuladas rápidas (*toggle clamps*)** sobre a borda reforçada da caixa. O mecanismo deve fazer um estalo suave ao cruzar o ponto morto central (*over-center*).

---

## 3. Protocolo de Desmontagem Rápida e Troca de Caixa (< 2 Minutos)

Se a caixa organizadora for danificada ou for necessário substituí-la por uma caixa com outra configuração de divisórias:

```
                      FLUXO DE SUBSTITUIÇÃO ULTRA-RÁPIDO
 [1. Desconectar Plugue Central] -> [2. Abrir 4 Presilhas Toggle] -> [3. Transferir Braços]
```

1. **Passo 1 (Elétrica)**: Desconectar o conector elétrico multipolar de engate rápido (padrão automotivo ou DB9/XT60) que liga a caixa aos braços.
2. **Passo 2 (Mecânica)**: Soltar manualmente as 4 alavancas das presilhas *toggle* (sem necessidade de nenhuma ferramenta).
3. **Passo 3 (Transferência)**: Erguer o conjunto estrutural completo de braços/rodas e assentá-lo sobre a nova caixa organizadora.
4. **Passo 4 (Travamento)**: Fechar as 4 alavancas *toggle* e reconectar o plugue elétrico.
* **Tempo Total Cronometrado**: $< 90\text{ segundos}$.

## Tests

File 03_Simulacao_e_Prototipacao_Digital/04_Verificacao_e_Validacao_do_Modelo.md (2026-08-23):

# 04. Verificação e Validação do Modelo de Simulação
## O que o modelo prova, o que ele não prova, e como saber a diferença

> Um simulador só vale como evidência de engenharia se o seu **domínio de
> validade** estiver declarado. Este documento faz o que R1 não fazia: separa
> **verificação** ("o código resolve corretamente as equações que escrevi?") de
> **validação** ("essas equações descrevem o rover real?"), e diz explicitamente
> quais conclusões ainda dependem de ensaio físico.

---

## 1. Arquitetura dos modelos

Existem três modelos, com propósitos diferentes e níveis diferentes de rigor:

```mermaid
graph LR
    A["<b>Modelo geométrico de marcha</b><br/>geometria_escada.py<br/>quase-estático, dirigido a eventos"]
    B["<b>Modelo dinâmico sagital</b><br/>multibody_dynamics.py<br/>7 GDL, passo fixo"]
    C["<b>Gêmeo digital em tempo real</b><br/>prototipo_3d/fisica.js<br/>4 rodas, 60+ fps"]

    A -->|"trajetória do cubo<br/>vira excitação de base"| B
    A -->|mesma parametrização de raio| C
    B -->|valores de referência| C

    A --> R1["Autoridade sobre:<br/>viabilidade da escalada,<br/>torque de içamento,<br/>queda de cubo"]
    B --> R2["Autoridade sobre:<br/>aceleração na carga,<br/>curso de suspensão"]
    C --> R3["Autoridade sobre:<br/>ergonomia de pilotagem,<br/>treinamento, demonstração"]
```

> **Hierarquia de autoridade.** Quando os três discordam, vale o modelo
> geométrico para questões de viabilidade e o modelo dinâmico para questões de
> carga. O gêmeo digital em tempo real faz aproximações em nome do desempenho e
> **não é evidência de engenharia** — é ferramenta de pilotagem e comunicação.

---

## 2. Hipóteses e domínio de validade

### 2.1. Modelo geométrico de marcha

| # | Hipótese | Consequência se violada |
| :--- | :--- | :--- |
| H1 | Movimento no plano sagital (sem guinada durante a subida) | aproximação oblíqua da escada não é coberta — daí a exigência de alinhamento ±5° no treinamento do piloto |
| H2 | Roda rígida; a complacência é tratada à parte | subestima a área de contato e superestima a nitidez das transições |
| H3 | Rolamento sem escorregamento no ponto de contato | válido enquanto μ_exigido < μ_disponível (verificado em §4) |
| H4 | Quase-estático: carga vertical constante no cubo | não captura efeitos inerciais em velocidade alta; válido até ~0,4 m/s na escada |
| H5 | Contato pontual amostrado ao longo da curva do raio | resolução de contato ≈ 1 mm com 220 amostras por raio |
| H6 | Terreno rígido e indeformável | válido para concreto; **inválido** para grama, brita ou areia |

**Domínio declarado:** escadas de concreto com E de 150 a 190 mm e P de 250 a
340 mm, aproximação frontal com desalinhamento ≤ 5°, velocidade ≤ 0,4 m/s.

### 2.2. Modelo dinâmico sagital

| # | Hipótese | Consequência se violada |
| :--- | :--- | :--- |
| H7 | Meio-veículo: eixos esquerdo e direito simétricos | não cobre degrau com um lado mais alto (escada danificada) |
| H8 | Excitação de base cinemática (a roda não altera o terreno) | válido; terreno rígido |
| H9 | Molas lineares com batente rígido | a não-linearidade real do elástico de borracha (histerese) é aproximada por amortecimento viscoso equivalente |
| H10 | Pêndulo da caixa com um grau de liberdade | não cobre balanço lateral da carga |
| H11 | Integração de Euler semi-implícito com ω·dt ≤ 0,10 | passo é calculado a partir da maior rigidez; configurações sem suspensão exigem passo menor (o código reduz automaticamente) |

### 2.3. Gêmeo digital em tempo real

| # | Aproximação | Motivo |
| :--- | :--- | :--- |
| H12 | Assentamento por quadro em vez de eventos de contato | custo computacional |
| H13 | Taxa de variação do alvo de contato limitada por \|dy/dt\| ≤ ω·r_max | corrige a descontinuidade introduzida por H12 — o assentamento a x fixo salta onde o terreno salta, o pivotamento real não |
| H14 | 26 amostras por raio (contra 220) | desempenho; resolução de contato ≈ 8 mm |
| H15 | Torque resistente estimado por fração da carga normal | evita resolver a geometria de contato completa a cada quadro |

---

## 3. Verificação (o código resolve o que foi escrito?)

73 verificações automatizadas em `testes/`. As mais significativas:

| Verificação | O que prova | Teste |
| :--- | :--- | :--- |
| Conservação de carga | Σ Fz = W·cos(θ) para toda inclinação | `test_cargas_somam_a_componente_normal_do_peso` |
| Reações não negativas | nenhuma roda "puxa" o solo | `test_reacoes_nunca_sao_negativas` |
| Ausência de interferência | nenhum ponto da roda penetra o terreno na marcha | `test_cubo_nunca_penetra_o_terreno` |
| Monotonicidade do avanço | o cubo nunca recua durante a marcha | `test_marcha_avanca_monotonicamente` |
| Fórmula analítica × numérica | alcance nariz-a-nariz bate com 2r·sin(π/N) | `test_alcance_nariz_a_nariz_bate_com_a_formula` |
| Solução analítica conhecida | ripple em piso plano = r(1−cos(π/N)) | `test_ripple_em_piso_plano_e_o_da_roda_sem_aro` |
| Inversibilidade | cinemática direta desfaz a inversa | `test_odometria_recupera_o_comando` |
| Restrição satisfeita | resíduo de deslizamento < 1e-12 m/s | `test_sem_arrasto_lateral` |
| Consistência de escala | kt ∝ t³/L | `test_kt_escala_com_o_cubo_da_espessura` |
| Estabilidade numérica | ω·dt ≤ 0,10 em toda configuração | `test_passo_de_integracao_respeita_a_frequencia_natural` |
| Coerência ida-e-volta | motor: corrente ↔ torque | `test_corrente_para_torque_e_inversa_do_ponto_de_operacao` |

**Casos com solução analítica conhecida** usados como referência:

1. **Roda sem aro em piso plano** — ripple teórico r(1−cos(π/N)) = 105 mm;
   simulado 94 mm (diferença de 10%, atribuída ao perfil curvo do raio, que
   suaviza a transferência em relação à roda de raios retos).
2. **Distribuição de cargas em plano** — W/4 por roda, exato.
3. **Alcance nariz-a-nariz** — corda do polígono inscrito, exato.
4. **Motor a vazio e em stall** — pontos extremos da curva, exatos.

---

## 4. Validação (as equações descrevem o rover real?)

> **Estado atual: o modelo NÃO está validado contra hardware.** Nenhuma peça foi
> fabricada. Todas as conclusões de R2 são **previsões**, e o documento de
> requisitos marca cada uma como 🟡 até o ensaio correspondente.

### 4.1. O que sustenta a confiança no modelo hoje

| Elemento | Base |
| :--- | :--- |
| Condição de marcha síncrona | geometria pura, sem parâmetro empírico |
| Fator 0,828 de correção FDM do C-STS | medido por Jeong & Kim (2025) em três espessuras |
| Coeficientes de atrito | faixas de literatura para borracha/concreto |
| Curva do motor | modelo clássico de motor CC com dados de catálogo |
| Resistência ao rolamento | faixas de Wong (2022) por tipo de piso |

### 4.2. O que é estimativa e precisa de medição

| Parâmetro | Valor usado | Confiança | Ensaio |
| :--- | ---: | :--- | :--- |
| Rigidez do feixe de elásticos | 1000 N/m | **baixa** — não medida | ENS-11 |
| Amortecimento histerético do feixe | 25 N·s/m | **baixa** | ENS-11 |
| Rigidez radial do aro elástico | 3500 N/m | **baixa** | ENS-04 |
| Força de colapso local do aro | 90 N | **baixa** | ENS-04 |
| R_th e C_th do motor | 8 K/W, 30 J/K | **média** — classe do motor | ENS-13 |
| Rendimento do redutor | 0,72 | média | ENS-02 |
| Inércia da roda | 0,0125 kg·m² | média — estimada em CAD | pesagem + pêndulo |
| μ borracha/concreto | 0,85 | média | ENS-06 |

> **Os quatro parâmetros de confiança baixa concentram-se na suspensão.** É por
> isso que ENS-04 e ENS-11 são pré-requisitos para a Fase 5, e não ensaios de
> conveniência.

### 4.3. Plano de validação

| Ensaio | Mede | Valida | Critério de aceite |
| :--- | :--- | :--- | :--- |
| ENS-04 | curva carga × deflexão do aro; força de colapso na aresta | H2, aro elástico | rigidez dentro de ±30% do modelo |
| ENS-11 | rigidez, histerese e deformação residual do feixe | H9, curso da suspensão | rigidez ±30%; residual < 15% em 50 ciclos |
| ENS-12 | fadiga da espiral C-STS | F-13 | 5000 ciclos sem perda > 10% de rigidez |
| ENS-13 | resposta térmica do motor sob corrente constante | modelo I²t | τ dentro de ±40% |
| ENS-06 | subida instrumentada com acelerômetro na carga | modelo dinâmico completo | pico vertical dentro de ±40% do previsto |
| ENS-01 | comparação firmware × simulador (β e v por roda) | cinemática | divergência ≤ 0,1° e 1 mm/s |

**Critério de validação do modelo:** ENS-06 é o teste integrador. Se o pico de
aceleração medido na carga durante uma subida real ficar dentro de ±40% do
previsto, o modelo é declarado validado para o domínio de §2.1. Fora disso, os
parâmetros de baixa confiança são reajustados **com os dados medidos** e a
predição é refeita — não o contrário.

---

## 5. Como reproduzir tudo

```bash
pip install -r requirements.txt

python3 -m simulador_python.main --parametros    # configuração resolvida
python3 -m simulador_python.main --marcha        # marcha na escada de referência
python3 -m simulador_python.main --sintese       # varredura do espaço de projeto
python3 -m simulador_python.main --benchmark     # figuras dos 6 benchmarks
python3 -m simulador_python.main --relatorio     # Relatório de Engenharia completo
python3 -m pytest testes/ -q                     # 73 verificações
```

Toda figura e todo número do Relatório de Engenharia são regenerados a partir do
arquivo mestre de parâmetros. **Nenhum resultado é digitado à mão.**

---

## 6. Registro de limitações conhecidas em aberto

1. **Aproximação oblíqua da escada** não é modelada (H1). Se a operação real
   exigir entrar em escadas em ângulo, é preciso um modelo 3D de contato.
2. **Terreno deformável** (grama, brita, areia) não é modelado (H6). A Fase A do
   roadmap depende disso — Wong (2022) cap. 2 e Shrivastava et al. (2020) dão a
   base para a extensão.
3. **Descida de escadas** não foi analisada com o mesmo rigor da subida. A
   dinâmica é diferente (gravidade ajuda, mas o risco de tombamento frontal
   cresce) e merece documento próprio antes da Fase 5.
4. **Histerese real do elástico de borracha** é aproximada por amortecimento
   viscoso. Elastômeros têm amortecimento dependente da frequência.
5. **Vida em fadiga de PETG impresso** não tem base experimental própria nem
   dados de literatura suficientes para o carregamento cíclico deste projeto.

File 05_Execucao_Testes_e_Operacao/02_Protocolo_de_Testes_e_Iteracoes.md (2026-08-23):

# 02. Protocolo de Testes Incrementais e Ciclo de Iterações
## Roteiro Experimental de Validação Física do Protótipo

> [!IMPORTANT]
> **Revisão R2 — expandido**
> Os cinco níveis de ensaio continuam válidos. Foram acrescentados os ensaios de **caracterização** que o modelo de simulação precisa para ser validado (ENS-04, ENS-11, ENS-12, ENS-13) — sem eles, os parâmetros de suspensão são estimativas. Ver [Verificação e Validação](../03_Simulacao_e_Prototipacao_Digital/04_Verificacao_e_Validacao_do_Modelo.md).
>
> Parâmetros vigentes: [`00_Especificacao_Mestre/00_Parametros_Mestres.md`](../00_Especificacao_Mestre/00_Parametros_Mestres.md) ·
> Achados: [`02_Auditoria_Tecnica.md`](../00_Especificacao_Mestre/02_Auditoria_Tecnica.md)

---

---

## 1. Metodologia de Testes Incrementais (Fase 4)

Para garantir que cada subsistema seja validado antes de ser submetido a estresses mecânicos severos, os ensaios são organizados em uma progressão de 5 níveis de complexidade:

```mermaid
graph LR
    T1[Nível 1: Bancada & Lógica] --> T2[Nível 2: Plano & Modos 4WS]
    T2 --> T3[Nível 3: Meio-fio & Obstáculos]
    T3 --> T4[Nível 4: Escadas & Carga Nominal]
    T4 --> T5[Nível 5: Endurance & Telemetria RF]
```

---

## 2. Roteiro dos Ensaios Físicos

| Nível de Teste | Procedimento Experimental | Parâmetros e Métricas de Aceite | Ação em Caso de Reprovação |
| :--- | :--- | :--- | :--- |
| **1. Bancada & Calibração** | Rover suspenso sem tocar o solo. Acionamento individual de cada motor e servo. | Corrente a vazio $< 0,8\text{A}$ por motor. Alinhamento de $0^\circ, 45^\circ, 90^\circ$ nos servos 4WS. | Ajuste de offsets de PWM no código do ESP32 e verificação mecânica de cabos. |
| **2. Solo Plano & Manobras** | Condução em piso liso e asfalto. Testar Ackermann duplo, caranguejo e giro no próprio eixo. | Resposta imediata aos comandos do rádio. Raio de giro no próprio eixo perfeitamente circular. | Calibração de ganho nos motores e alinhamento das mangas de eixo. |
| **3. Meio-fio e Desníveis** | Transposição frontal e em ângulo de meio-fio urbano de $12 \text{ cm}$ e $15 \text{ cm}$. | Engate suave do raio curvo sem parada do motor e sem derrapagem excessiva. | Aumentar a tensão dos elásticos de suspensão ou aplicar banda de borracha nos raios. |
| **4. Subida de Escadas com Carga** | Subida de 1 lance de escada padrão com peso simulado de $3,0 \text{ kg}$ na caixa organizadora. | Não tombar para trás. Aceleração vertical de choque na carga $< 2,0g$. | Rebaixar mais os pesos para o fundo da caixa ou aumentar a pré-tensão elástica. |
| **5. Teste de Rádio e Failsafe** | Operador a 300m de distância em ambiente com obstáculos prediais. Desligar o transmissor propositalmente. | Failsafe deve parar os motores em $< 300\text{ ms}$. Vídeo FPV sem congelamentos severos. | Otimizar posicionamento das antenas de 5.8GHz e 915MHz no alto da caixa. |

---

## 3. Matriz de Iteração e Ajustes Práticos

```mermaid
flowchart TD
    Start[Identificação de Anomalia no Teste] --> Type{Qual é o sintoma?}
    
    Type -->|Escorregamento na quina da escada| A1[Adicionar revestimento de câmara de ar nos raios curvos]
    Type -->|Choque brusco ao mudar de raio| A2[Aumentar a flexibilidade: reduzir de 6 para 4 elásticos]
    Type -->|Braço afunda excessivamente sob peso| A3[Aumentar rigidez: adicionar +2 elásticos por braço]
    Type -->|Motor trava no meio do degrau| A4[Aumentar redução mecânica ou ajustar limite de PWM do driver]
    Type -->|Caixa oscila em excesso| A5[Verificar aperto das abraçadeiras e rebaixar baterias para o fundo]
```

---

## 4. Teste de Fadiga e Durabilidade dos Elásticos

* **Procedimento**: Submissão do rover a 50 ciclos consecutivos de subida de rampa e 20 subidas de degrau.
* **Critério de Inspeção**: Medição do comprimento em repouso dos elásticos antes e depois do teste.
* **Limite de Deformação Plástica**: Se o alongamento residual permanente ultrapassar $15\%$, descarta-se o feixe e instala-se um conjunto novo.

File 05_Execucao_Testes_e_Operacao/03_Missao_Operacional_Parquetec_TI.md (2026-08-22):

# 03. Missão Operacional de Homologação: Resgate e Entrega de Notebook na T.I.
## Roteiro Executivo da Prova de Sucesso no Itaipu Parquetec

---

## 1. Contexto e Definição da Missão

A **Fase 5** é o ápice executivo do projeto. A missão simula um caso de uso real de logística predial no campus do **Itaipu Parquetec**: um funcionário ou pesquisador em um edifício remoto solicita a entrega de um notebook institucional para a equipe de Tecnologia da Informação (T.I.) para manutenção urgente.

```mermaid
graph LR
    subgraph 1. Ponto de Partida
        Base[Laboratório / Base do Rover]
    end

    subgraph 2. Percurso de Ida
        Base -->|Navegação Mista: Asfalto + Rampas + Calçadas| Remoto[Edifício / Ponto Remoto do Solicitante]
    end

    subgraph 3. Embarque da Carga
        Remoto -->|Acomodação do Notebook na Caixa Organizadora| Carga[Carga Útil Travada]
    end

    subgraph 4. Percurso de Retorno
        Carga -->|Subida de Escadas + Corredores Internos| TI[Departamento de T.I. do Parquetec]
    end

    subgraph 5. Homologação Final
        TI -->|Entrega do Notebook + Teste de Funcionamento| Conclusao[Declaração Oficial de Sucesso]
    end
```

---

## 2. Roteiro e Fases da Operação de Campo

### Fase A: Checklist Pré-Missão (*Briefing & Pre-Flight Check*)
1. Verificar carga das baterias principais ($\ge 12,4\text{V}$ para 3S ou $\ge 16,4\text{V}$ para 4S).
2. Verificar integridade e tensão dos elásticos de escritório nas 4 pernas.
3. Testar resposta dos 4 servos 4WS e dos 4 motores 4WD pelo rádio transmissor.
4. Confirmar nitidez da transmissão de vídeo FPV de 5.8GHz e telemetria na tela do piloto.
5. Iniciar gravação contínua da câmera externa e dos logs do acelerômetro embarcado.

### Fase B: Deslocamento até o Solicitante (Trecho de Ida)
* O piloto, posicionado na estação de comando, guia o rover pelo campus do parque.
* O rover vence meios-fios e irregularidades no trajeto até chegar à porta da sala do solicitante.

### Fase C: Embarque Seguro do Equipamento
* O usuário abre a tampa da caixa organizadora plástica do rover.
* O notebook corporativo (peso médio $\sim 2,2 \text{ kg}$) é acomodado sobre a camada interna de espuma absorvente de impacto no fundo da caixa.
* A tampa da caixa é travada por fecho rápido.

### Fase D: Deslocamento com Carga até a T.I. (Trecho Crítico de Retorno)
* O piloto conduz o UGV de volta, enfrentando os lances de escadas externos ou internos do prédio da T.I.
* O rover sobe os degraus utilizando as rodas *curved spokes*, com a suspensão elástica absorvendo os picos de aceleração e o efeito pendular mantendo o centro de gravidade rebaixado.
* O veículo adentra a porta do departamento de T.I. utilizando manobra em Ackermann duplo ou caranguejo se o vão for estreito.

### Fase E: Desembarque e Validação Funcional
* A equipe de T.I. recebe o rover, abre a caixa e retira o notebook.
* **Teste de Integridade Imediato**: O notebook é ligado na presença de testemunhas e da equipe avaliadora, comprovando que o disco, a tela e o hardware estão 100% íntegros e operacionais.

---

## 3. Ata de Homologação e Conclusão Executiva

Cumprida a missão sem intervenção física humana no rover durante o trajeto (exceto o embarque do notebook) e comprovada a integridade do equipamento:
1. É emitida a **Ata de Conclusão da Prova de Conceito**.
2. Declara-se encerrada com sucesso a fase executiva principal do projeto (Fase 6).
3. Habilita-se formalmente o início do desenvolvimento dos roadmaps de longo alcance e da versão tática com fibra óptica (Fase 7).

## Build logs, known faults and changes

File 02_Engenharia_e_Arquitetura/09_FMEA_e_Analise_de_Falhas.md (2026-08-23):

# 09. FMEA — Análise de Modos de Falha e Efeitos
## Da matriz qualitativa de riscos para uma análise com RPN e ações verificáveis

> R1 tinha uma matriz probabilidade × impacto com seis riscos posicionados por
> julgamento. Aqui os modos de falha são levantados **por subsistema**, com
> severidade, ocorrência, detecção e ação — no formato clássico de FMEA de
> produto. Vários modos só ficaram visíveis depois da análise física de R2.

**Escalas (1 a 10).**
**S** severidade do efeito · **O** probabilidade de ocorrência ·
**D** dificuldade de detecção antes do efeito · **RPN = S × O × D**.

**Critério de ação:** RPN ≥ 100 exige ação de projeto antes da Fase 4;
RPN ≥ 200 é bloqueante.

---

## 1. Subsistema: roda e contato com o solo

| # | Modo de falha | Efeito | S | O | D | RPN | Ação |
| :--- | :--- | :--- | :-: | :-: | :-: | --: | :--- |
| F-01 | Aro elástico rígido demais: não colapsa na quina | roda não engata, não sobe | 9 | 5 | 3 | **135** | ENS-04 mede a força de colapso antes da montagem final; aro segmentado com molas de lâmina como plano B |
| F-02 | Aro elástico macio demais: colapsa em piso plano | ripple de 105 mm, choque na carga | 8 | 4 | 2 | 64 | mesma calibração ENS-04; telemetria de `carga_vert_g` detecta em operação |
| F-03 | Fratura de raio curvo no impacto contra a quina | perda de tração, missão abortada | 8 | 4 | 3 | 96 | impressão deitada (camadas acompanham a curvatura), 5 perímetros, 100% de preenchimento na raiz; banco de rodas reserva |
| F-04 | Desgaste da pastilha de borracha da ponta | atrito cai abaixo de 0,72, escorrega | 7 | 5 | 4 | **140** | pastilha substituível por parafuso; inspeção antes de cada missão; verificação de μ no ENS-06 |
| F-05 | Roda escorrega na face do espelho | não sobe, pode descer de volta | 9 | 3 | 3 | 81 | resolvido por projeto (marcha síncrona, [A-01](../00_Especificacao_Mestre/02_Auditoria_Tecnica.md#a-01)); detecção por discrepância odometria × IMU |
| F-06 | Piso molhado ou polido | atrito insuficiente, escorregamento | 9 | 5 | 2 | 90 | bloqueio do modo escada com confirmação do piloto ([A-10](../00_Especificacao_Mestre/02_Auditoria_Tecnica.md#a-10)) |

---

## 2. Subsistema: suspensão

| # | Modo de falha | Efeito | S | O | D | RPN | Ação |
| :--- | :--- | :--- | :-: | :-: | :-: | --: | :--- |
| F-10 | Ruptura de elástico do feixe | rigidez cai, curso satura | 5 | 7 | 2 | 70 | feixe redundante (8 unidades: perder 1 muda 12,5%); troca em < 30 s; substituição preventiva a cada 10 ciclos |
| F-11 | Deformação plástica acumulada do feixe | afundamento estático cresce, ventre encosta no nariz | 7 | 6 | 5 | **210** ⛔ | ENS-11 mede a deformação residual; **calço de ajuste** no projeto do braço para recuperar a altura; considerar mola helicoidal comercial se residual > 15% |
| F-12 | Espiral C-STS bate no batente a cada transferência | choque transmitido, fadiga da lâmina | 6 | 4 | 4 | 96 | dimensionada para 30° com batente em 35°; deflexão vai na telemetria |
| F-13 | Fadiga da lâmina C-STS em PETG | perda de rigidez progressiva | 7 | 4 | 6 | **168** | FS 4,4 em tensão estática, mas **vida em fadiga do PETG impresso é desconhecida**: ENS-12 com 5000 ciclos antes da Fase 5 |
| F-14 | Batente de fim de curso quebra | sobre-extensão destrói os elásticos | 6 | 3 | 3 | 54 | batente metálico (parafuso + porca) em vez de impresso |

---

## 3. Subsistema: tração e energia

| # | Modo de falha | Efeito | S | O | D | RPN | Ação |
| :--- | :--- | :--- | :-: | :-: | :-: | --: | :--- |
| F-20 | Sobretemperatura do enrolamento em lances consecutivos | queima do motor | 9 | 6 | 5 | **270** ⛔ | proteção I²t obrigatória ([A-08](../00_Especificacao_Mestre/02_Auditoria_Tecnica.md#a-08)); pausa de resfriamento imposta; NTC de calibração no ENS-13 |
| F-21 | Célula não sustenta 4,6C de pico | queda de tensão, reset do MCU | 8 | 4 | 3 | 96 | REQ-303 verifica o datasheet antes da compra; capacitor de tampão no barramento |
| F-22 | Driver BTS7960 em proteção térmica sob carga | perda de tração de uma roda | 7 | 4 | 3 | 84 | dissipador + ventilação forçada; margem de 200% na corrente nominal |
| F-23 | Redutor planetário com folga (*backlash*) | odometria e controle degradados | 5 | 6 | 5 | 150 | redutor metálico (não plástico); folga medida no ENS-02 e compensada |
| F-24 | Acoplador da roda solta sob torque de içamento | roda gira solta, perda de tração | 8 | 4 | 4 | 128 | acoplador sextavado com dois prisioneiros a 90° e trava química; verificação no checklist pré-missão |

---

## 4. Subsistema: esterçamento 4WS

| # | Modo de falha | Efeito | S | O | D | RPN | Ação |
| :--- | :--- | :--- | :-: | :-: | :-: | --: | :--- |
| F-30 | Erro de calibração de um servo | arrasto lateral, corrente extra, desvio de rota | 5 | 7 | 6 | **210** ⛔ | rotina de calibração no ENS-02 com erro ≤ 1,0° ([A-05](../00_Especificacao_Mestre/02_Auditoria_Tecnica.md#a-05)); referência mecânica (pino) na manga |
| F-31 | Servo sem resposta (engrenagem quebrada) | sistema sobre-restrito trava (δm = 0) | 9 | 3 | 2 | 54 | servo com realimentação de posição; supervisor detecta e trava o modo |
| F-32 | Saturação de esterçamento não sinalizada | odometria erra silenciosamente | 4 | 6 | 7 | 168 | flag de saturação no OSD e na telemetria ([A-05](../00_Especificacao_Mestre/02_Auditoria_Tecnica.md#a-05)) |
| F-33 | Rolamento 608ZZ da manga travado por poeira | esterçamento duro, servo satura | 5 | 5 | 4 | 100 | vedação labiríntica na manga; lubrificação no checklist |

---

## 5. Subsistema: estrutura e carga

| # | Modo de falha | Efeito | S | O | D | RPN | Ação |
| :--- | :--- | :--- | :-: | :-: | :-: | --: | :--- |
| F-40 | Junta split-clamp escorrega no tubo de PVC | geometria muda, roda desalinha | 7 | 5 | 5 | **175** | torque de aperto especificado (1,8 a 2,2 N·m); marca de referência pintada no tubo denuncia deslizamento visualmente |
| F-41 | Trinca no PVC por sobreaperto do clamp | perda estrutural do braço | 8 | 4 | 6 | 192 | torquímetro obrigatório na montagem; inspeção visual das orelhas |
| F-42 | Presilha toggle abre sob vibração | caixa se solta dos braços | 10 | 2 | 3 | 60 | presilha com trava secundária (contrapino); verificação no checklist pré-missão |
| F-43 | Notebook desliza dentro da caixa | choque lateral no equipamento | 6 | 6 | 3 | 108 | berço de espuma recortado + cinta de velcro; ENS-08 valida com acelerômetro na carga |
| F-44 | Ventre encosta no nariz do degrau | trava no meio do lance | 8 | 3 | 2 | 48 | vão livre de 190 mm por projeto, com dois critérios ([06](06_Sintese_da_Roda_e_Geometria_de_Escalada.md) §4.2) |

---

## 6. Subsistema: controle e teleoperação

| # | Modo de falha | Efeito | S | O | D | RPN | Ação |
| :--- | :--- | :--- | :-: | :-: | :-: | --: | :--- |
| F-50 | Perda de enlace dentro do prédio | rover parado em local inacessível | 7 | 6 | 2 | 84 | failsafe em 300 ms + retorno assistido; ELRS 915 MHz; teste de cobertura no ENS-10 |
| F-51 | Failsafe deixa as rodas livres em rampa | rover desce sozinho | 9 | 3 | 3 | 81 | freio dinâmico por curto nas pontes H |
| F-52 | Limiar anti-tombamento aborta subida normal | missão não completa | 6 | 8 | 2 | 96 | limiar dependente de modo ([A-09](../00_Especificacao_Mestre/02_Auditoria_Tecnica.md#a-09)) |
| F-53 | Latência de vídeo alta engana o piloto | manobra errada, colisão | 6 | 4 | 4 | 96 | VTX analógico ≤ 50 ms; medição no ENS-10 |
| F-54 | Odometria errada por complacência do C-STS | posição estimada diverge | 4 | 8 | 6 | 192 | encoder no lado da roda ou compensação explícita ([A-04](../00_Especificacao_Mestre/02_Auditoria_Tecnica.md#a-04)) |

---

## 7. Consolidado: o que precisa ser resolvido antes da Fase 4

| RPN | Modo | Bloqueio |
| ---: | :--- | :--- |
| **270** | F-20 sobretemperatura do motor | ⛔ proteção I²t implementada e testada |
| **210** | F-11 deformação plástica dos elásticos | ⛔ ENS-11 concluído com critério de aceite |
| **210** | F-30 calibração dos servos 4WS | ⛔ rotina de calibração validada (ENS-02) |
| **192** | F-41 trinca no PVC por sobreaperto | torquímetro na bancada |
| **192** | F-54 odometria x complacência do C-STS | decisão sobre posição do encoder |
| **175** | F-40 escorregamento do split-clamp | procedimento com marca de referência |
| **168** | F-13 fadiga do C-STS em PETG | ENS-12 com 5000 ciclos |
| **168** | F-32 saturação silenciosa | flag na telemetria |
| **150** | F-23 folga do redutor | medição e compensação |
| **140** | F-04 desgaste da pastilha | pastilha substituível |
| **135** | F-01 janela de colapso do aro | ENS-04 |

```mermaid
quadrantChart
    title Modos de falha — ocorrência x severidade (tamanho = dificuldade de detecção)
    x-axis "Baixa severidade" --> "Alta severidade"
    y-axis "Baixa ocorrência" --> "Alta ocorrência"
    quadrant-1 "Monitorar de perto"
    quadrant-2 "Prioridade crítica"
    quadrant-3 "Aceitar"
    quadrant-4 "Prevenir por projeto"
    "F-20 térmica do motor": [0.90, 0.60]
    "F-11 fadiga dos elásticos": [0.70, 0.60]
    "F-30 calibração 4WS": [0.50, 0.70]
    "F-54 odometria C-STS": [0.40, 0.80]
    "F-13 fadiga do C-STS": [0.70, 0.40]
    "F-01 aro não colapsa": [0.90, 0.50]
    "F-40 clamp escorrega": [0.70, 0.50]
    "F-42 presilha abre": [1.00, 0.20]
    "F-50 perda de enlace": [0.70, 0.60]
```

---

## 8. O que mudou em relação à matriz de riscos de R1

| Risco de R1 | Situação em R2 |
| :--- | :--- |
| R1 fadiga dos elásticos | mantido e agravado (F-11, RPN 210): o curso de 90 mm exige mais dos elásticos |
| R2 fratura de raios curvos | mantido (F-03), com ação de orientação de impressão |
| R3 superaquecimento dos drivers | **reclassificado**: o gargalo térmico é o **motor** (F-20), não o driver |
| R4 latência de rádio | mantido (F-50, F-53) |
| R5 desalinhamento dos braços de PVC | desdobrado em F-40 e F-41, com procedimento de aperto |
| R6 atraso na entrega de peças | risco de cronograma, migrado para `01_Planejamento/03` |
| — | **novo:** F-01/F-02, janela de operação do aro elástico |
| — | **novo:** F-20, limite térmico dos motores |
| — | **novo:** F-30/F-54, consequências do sistema sobre-restrito e da complacência |
| — | **novo:** F-06, atrito insuficiente em piso molhado |

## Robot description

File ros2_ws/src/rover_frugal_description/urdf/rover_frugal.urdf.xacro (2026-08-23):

<?xml version="1.0"?>
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
<robot xmlns:xacro="http://www.ros.org/wiki/xacro" name="rover_frugal">

  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
  <xacro:arg name="aro_elastico" default="true"/>
  <xacro:arg name="usar_ros2_control" default="true"/>
  <xacro:arg name="controladores" default="$(find rover_frugal_control)/config/controladores.yaml"/>

  <xacro:property name="cfg" value="${xacro.load_yaml('$(find rover_frugal_description)/config/parametros.yaml')}"/>
  <xacro:property name="R" value="${cfg['roda']}"/>
  <xacro:property name="V" value="${cfg['veiculo']}"/>
  <xacro:property name="M" value="${cfg['massas']}"/>
  <xacro:property name="I" value="${cfg['inercias']}"/>
  <xacro:property name="J" value="${cfg['juntas']}"/>
  <xacro:property name="C" value="${cfg['contato']}"/>
  <xacro:property name="POS" value="${cfg['posicoes_rodas']}"/>
  <xacro:property name="ESF" value="${cfg['colisao_raios']}"/>
  <xacro:property name="PONTAS" value="${cfg['colisao_pontas']}"/>
  <xacro:property name="malhas" value="package://rover_frugal_description/meshes"/>

  <xacro:property name="com_aro" value="$(arg aro_elastico)"/>

  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

  <xacro:macro name="inercial" params="massa i:=^ *origin">
    <inertial>
      <xacro:insert_block name="origin"/>
      <mass value="${massa}"/>
      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
    </inertial>
  </xacro:macro>

  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
  <xacro:macro name="esferas_pontas" params="prefixo lista sinal indice:=0">
    <xacro:if value="${lista != []}">
      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
      <xacro:esferas_pontas prefixo="${prefixo}" lista="${lista[1:]}" sinal="${sinal}" indice="${indice + 1}"/>
    </xacro:if>
  </xacro:macro>

  <xacro:macro name="esferas_raios" params="lista sinal">
    <xacro:if value="${lista != []}">
      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
      <xacro:esferas_raios lista="${lista[1:]}" sinal="${sinal}"/>
    </xacro:if>
  </xacro:macro>

  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
  <link name="base_footprint"/>

  <joint name="base_footprint_joint" type="fixed">
    <parent link="base_footprint"/>
    <child link="base_link"/>
    <origin xyz="0 0 ${R['raio_max']}" rpy="0 0 0"/>
  </joint>

  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
  <link name="base_link">
    <xacro:inercial massa="${M['base']}" i="${I['base']}">
      <origin xyz="0 0 ${V['offset_cg_eixo']}" rpy="0 0 0"/>
    </xacro:inercial>

    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
  </link>

  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
  <xacro:macro name="braco" params="prefixo">
    <xacro:property name="p" value="${POS[prefixo]}"/>
    <link name="braco_${prefixo}">
      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
    </link>
    <joint name="braco_${prefixo}_joint" type="fixed">
      <parent link="base_link"/>
      <child link="braco_${prefixo}"/>
      <origin xyz="0 0 0" rpy="0 0 0"/>
    </joint>
  </xacro:macro>

  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
  <xacro:macro name="conjunto_roda" params="prefixo">
    <xacro:property name="p" value="${POS[prefixo]}"/>
    <xacro:property name="ex" value="${p['eixo'][0]}"/>
    <xacro:property name="ey" value="${p['eixo'][1]}"/>
    <xacro:property name="lado" value="${1 if p['eixo'][1] > 0 else -1}"/>

    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
    <link name="suporte_${prefixo}">
      <xacro:inercial massa="${M['suporte']}" i="${I['suporte']}">
        <origin xyz="0 0 0" rpy="0 0 0"/>
      </xacro:inercial>
      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
    </link>
    <joint name="susp_${prefixo}" type="prismatic">
      <parent link="base_link"/>
      <child link="suporte_${prefixo}"/>
      <origin xyz="${ex} ${ey} 0" rpy="0 0 0"/>
      <axis xyz="0 0 1"/>
      <limit lower="${J['suspensao']['limite_inferior']}" upper="${J['suspensao']['limite_superior']}" effort="${J['suspensao']['esforco_maximo']}" velocity="${J['suspensao']['velocidade_maxima']}"/>
      <dynamics damping="${J['suspensao']['amortecimento']}" friction="0.5"/>
    </joint>

    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
    <link name="manga_${prefixo}">
      <xacro:inercial massa="${M['manga']}" i="${I['manga']}">
        <origin xyz="0 0 0.03" rpy="0 0 0"/>
      </xacro:inercial>
      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
    </link>
    <joint name="esterco_${prefixo}" type="revolute">
      <parent link="suporte_${prefixo}"/>
      <child link="manga_${prefixo}"/>
      <origin xyz="0 0 0" rpy="0 0 0"/>
      <axis xyz="0 0 1"/>
      <limit lower="${-J['estercamento']['limite_rad']}" upper="${J['estercamento']['limite_rad']}" effort="${J['estercamento']['esforco_maximo']}" velocity="${J['estercamento']['velocidade_maxima']}"/>
      <dynamics damping="${J['estercamento']['amortecimento']}" friction="0.02"/>
    </joint>

    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
    <link name="cubo_${prefixo}">
      <xacro:inercial massa="${M['cubo']}" i="${I['cubo']}">
        <origin xyz="0 0 0" rpy="0 0 0"/>
      </xacro:inercial>
      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
    </link>
    <joint name="tracao_${prefixo}" type="continuous">
      <parent link="manga_${prefixo}"/>
      <child link="cubo_${prefixo}"/>
      <origin xyz="0 0 0" rpy="0 0 0"/>
      <axis xyz="0 1 0"/>
      <limit effort="${J['tracao']['esforco_maximo']}" velocity="${J['tracao']['velocidade_maxima']}"/>
      <dynamics damping="${J['tracao']['amortecimento']}" friction="${J['tracao']['atrito']}"/>
    </joint>

    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
    <link name="roda_${prefixo}">
      <xacro:inercial massa="${M['roda']}" i="${I['roda']}">
        <origin xyz="0 0 0" rpy="0 0 0"/>
      </xacro:inercial>

      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

      <xacro:if value="${com_aro}">
        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
      </xacro:if>

      <xacro:unless value="${com_aro}">
        <xacro:esferas_raios lista="${ESF}" sinal="${lado}"/>
        <xacro:esferas_pontas prefixo="${prefixo}" lista="${PONTAS}" sinal="${lado}"/>
      </xacro:unless>
    </link>
    <joint name="csts_${prefixo}" type="revolute">
      <parent link="cubo_${prefixo}"/>
      <child link="roda_${prefixo}"/>
      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
      <origin xyz="0 0 0" rpy="0 0 0"/>
      <axis xyz="0 1 0"/>
      <limit lower="${-J['csts']['limite_rad']}" upper="${J['csts']['limite_rad']}" effort="${J['csts']['esforco_maximo']}" velocity="${J['csts']['velocidade_maxima']}"/>
      <dynamics damping="${J['csts']['amortecimento']}" friction="0.01"/>
    </joint>

    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
  </xacro:macro>

  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
  <xacro:braco prefixo="FL"/>
  <xacro:braco prefixo="FR"/>
  <xacro:braco prefixo="RL"/>
  <xacro:braco prefixo="RR"/>

  <xacro:conjunto_roda prefixo="FL"/>
  <xacro:conjunto_roda prefixo="FR"/>
  <xacro:conjunto_roda prefixo="RL"/>
  <xacro:conjunto_roda prefixo="RR"/>

  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
  <link name="camera_fpv"/>
  <joint name="camera_fpv_joint" type="fixed">
    <parent link="base_link"/>
    <child link="camera_fpv"/>
    <origin xyz="${V['profundidade_caixa']/2 + 0.02} 0 ${V['vao_livre'] - R['raio_max'] + V['altura_caixa'] - 0.04}" rpy="0 0 0"/>
  </joint>

  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
  <link name="imu_link"/>
  <joint name="imu_joint" type="fixed">
    <parent link="base_link"/>
    <child link="imu_link"/>
    <origin xyz="0 0 ${V['vao_livre'] - R['raio_max'] + 0.02}" rpy="0 0 0"/>
  </joint>

  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

  <xacro:include filename="$(find rover_frugal_description)/urdf/sensores.gazebo.xacro"/>

  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
  <xacro:if value="$(arg usar_ros2_control)">
    <ros2_control name="RoverFrugalSim" type="system">
      <hardware>
        <plugin>gz_ros2_control/GazeboSimSystem</plugin>
      </hardware>

      <xacro:macro name="interfaces_roda" params="prefixo">
        <joint name="esterco_${prefixo}">
          <command_interface name="position">
            <param name="min">${-J['estercamento']['limite_rad']}</param>
            <param name="max">${J['estercamento']['limite_rad']}</param>
          </command_interface>
          <state_interface name="position"/>
          <state_interface name="velocity"/>
          <state_interface name="effort"/>
        </joint>

        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
        <joint name="tracao_${prefixo}">
          <command_interface name="effort">
            <param name="min">${-J['tracao']['esforco_maximo']}</param>
            <param name="max">${J['tracao']['esforco_maximo']}</param>
          </command_interface>
          <state_interface name="position"/>
          <state_interface name="velocity"/>
          <state_interface name="effort"/>
        </joint>
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

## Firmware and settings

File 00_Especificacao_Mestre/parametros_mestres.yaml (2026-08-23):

# =============================================================================
#  PARÂMETROS MESTRES DO PROJETO ROVER FRUGAL 4WD/4WS
#  Fonte única de verdade (Single Source of Truth) do projeto.
#
#  Este arquivo é consumido por:
#    - simulador_python/config.py        (simulador físico e ferramentas de análise)
#    - ferramentas/gerar_parametros_js.py (gera prototipo_3d/parametros.js)
#    - ferramentas/gerar_documentacao.py  (gera 00_Especificacao_Mestre/00_Parametros_Mestres.md)
#
#  REGRA DE OURO: nenhum número de engenharia deve ser escrito diretamente em
#  código ou em documento. Todo valor dimensional, de massa, elétrico ou de
#  desempenho vive aqui e é referenciado pela sua chave.
#
#  Unidades: SI estrito (m, kg, s, N, W, V, A, rad) salvo sufixo explícito.
# =============================================================================

meta:
  projeto: "Rover Frugal 4WD/4WS — UGV de Inovação Frugal para Logística Predial"
  revisao: "R2"
  data_revisao: "2026-08-22"
  variante_ativa: "v2_sincrona"
  descricao_revisao: >
    R2 consolida a auditoria técnica (00_Especificacao_Mestre/02_Auditoria_Tecnica.md),
    corrige o dimensionamento da roda pela condição de marcha síncrona de raios,
    unifica massas, raios e contagem de raios entre documentos e código, e
    corrige a classificação cinemática de Siegwart (δm=1, δs=2, δM=3).

# -----------------------------------------------------------------------------
# 1. AMBIENTE OPERACIONAL DE REFERÊNCIA
# -----------------------------------------------------------------------------
ambiente:
  # Escada civil de referência (ABNT NBR 9050 / Lei de Blondel 2E + P = 0,63–0,65 m)
  escada:
    espelho_E: 0.170          # altura do degrau (riser) [m]
    piso_P: 0.300             # profundidade do degrau (tread) [m]
    largura: 1.200            # largura útil do lance [m]
    num_degraus_lance: 8      # degraus por lance típico do campus
    # Derivados (calculados em código, aqui apenas para conferência humana):
    #   blondel = 2E + P = 0.640 m          -> conforme NBR 9050
    #   passo_D = hypot(E, P) = 0.3448 m    -> distância nariz-a-nariz
    #   inclinacao = atan(E/P) = 29.54 deg
  meio_fio:
    altura_tipica: 0.120
    altura_maxima: 0.150
  piso:
    mu_borracha_concreto: 0.85      # atrito estático borracha vulcanizada/concreto
    mu_borracha_concreto_molhado: 0.55
    mu_borracha_marmore_polido: 0.40  # pior caso: hall de entrada encerado
    crr_asfalto: 0.030              # resistência ao rolamento em asfalto/calçada
    crr_grama: 0.110
  porta_estreita: 0.800             # vão livre mínimo de porta a transpor [m]
  corredor_estreito: 0.900

# -----------------------------------------------------------------------------
# 2. GEOMETRIA E MASSAS DO VEÍCULO (variante ativa)
# -----------------------------------------------------------------------------
veiculo:
  # Base de rodas dimensionada como múltiplo inteiro do passo do degrau
  # (L = k * D) para travar a fase entre eixo dianteiro e traseiro na escada.
  entre_eixos_L: 0.690        # 2 x passo do degrau (2 x 0.3448) [m]
  bitola_W: 0.600             # bitola transversal [m]
  fator_fase_escada_k: 2      # L = k * D_passo
  # Alturas coerentes com a caixa organizadora apoiada no vão livre:
  #   fundo da caixa (ventre) a 190 mm; caixa de ~250 mm de altura interna;
  #   notebook e bateria deitados no fundo sobre espuma -> CG da carga a 225 mm;
  #   braços, mangas, motores e rodas em torno do eixo (210 mm) e da braçadeira
  #   superior (357 mm) -> CG do conjunto seco a 280 mm.
  altura_cg_chassi: 0.280
  altura_cg_carga: 0.225
  altura_caixa: 0.250
  altura_fixacao_pendular: 0.357   # terço superior da caixa: 190 + 2/3 x 250
  # Folga do ventre: dois critérios, vale o maior.
  #  (a) linha dos narizes — o simulador mede 79 mm de espaço abaixo do eixo no
  #      pior caso: ventre >= 210 - 79 + 20 = 151 mm;
  #  (b) aproximação frontal do primeiro degrau: ventre >= espelho + margem
  #      = 170 + 20 = 190 mm.  <- critério dominante
  vao_livre_ventre: 0.190     # menor cota do ventre (fundo da caixa) ao piso [m]
  folga_ventre_medida: 0.079  # pior caso medido por simulador_python.geometria_escada [m]
  braco_pendular: 0.160       # ponto de fixação (1/3 superior) ao CG da carga [m]
  amortecimento_pendular: 4.5
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

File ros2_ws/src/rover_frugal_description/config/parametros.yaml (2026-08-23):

# ARQUIVO GERADO — não editar à mão.
# Fonte: 00_Especificacao_Mestre/parametros_mestres.yaml
# Gerador: ferramentas/gerar_ros_config.py

_gerado_por: ferramentas/gerar_ros_config.py
_fonte: 00_Especificacao_Mestre/parametros_mestres.yaml
_aviso: ARQUIVO GERADO — não editar à mão.
revisao: R2
roda: {raio_max: 0.21, raio_cubo: 0.07, largura: 0.024, num_raios: 3, raio_com_aro: 0.21,
  largura_com_aro: 0.034, afundamento_aro_nominal: 0.007025764249999998}
veiculo: {entre_eixos: 0.69, bitola: 0.6, vao_livre: 0.19, altura_cg: 0.28, offset_cg_eixo: 0.07000000000000003,
  largura_caixa: 0.369, profundidade_caixa: 0.37499999999999994, altura_caixa: 0.25,
  altura_fixacao: 0.357}
envelope: {largura_m: 0.664, comprimento_m: 1.1099999999999999, altura_m: 0.47, passa_em_porta: true,
  folga_na_porta_mm: 136.0, passa_em_corredor: true, raio_de_giro_m: 0.6671925196238451}
massas: {base: 5.589999999999998, suporte: 0.03, manga: 0.2125, cubo: 0.23, roda: 0.6375,
  total: 10.029999999999998}
inercias:
  base: {ixx: 0.09462239583333328, iyy: 0.0925429158333333, izz: 0.12893614499999995,
    ixy: 0.0, ixz: 0.0, iyz: 0.0}
  suporte: {ixx: 1.25e-05, iyy: 1.25e-05, izz: 1.25e-05, ixy: 0.0, ixz: 0.0, iyz: 0.0}
  manga: {ixx: 0.00024083333333333335, iyy: 0.00024083333333333335, izz: 0.00012749999999999998,
    ixy: 0.0, ixz: 0.0, iyz: 0.0}
  cubo: {ixx: 0.000138, iyy: 0.000138, izz: 0.000138, ixy: 0.0, ixz: 0.0, iyz: 0.0}
  roda: {ixx: 0.00625, iyy: 0.0125, izz: 0.00625, ixy: 0.0, ixz: 0.0, iyz: 0.0}
juntas:
  suspensao: {curso: 0.09, limite_inferior: 0.0, limite_superior: 0.09, rigidez: 1000.0,
    amortecimento: 25.0, afundamento_estatico: 0.022, esforco_maximo: 135.0, velocidade_maxima: 1.0}
  estercamento: {limite_rad: 0.9599310885968813, esforco_maximo: 2.45, velocidade_maxima: 5.24,
    amortecimento: 0.05}
  tracao: {esforco_maximo: 12.487021352252249, velocidade_maxima: 7.306029426953007,
    amortecimento: 0.01, atrito: 0.02}
  csts: {limite_rad: 0.6108652381980153, rigidez: 12.3, amortecimento: 0.08, esforco_maximo: 11.270463644753383,
    velocidade_maxima: 20.0}
contato: {mu_seco: 0.85, mu_molhado: 0.55, mu_polido: 0.4, kp_aro: 3500.0, kd_aro: 40.0,
  kp_rigido: 100000.0, kd_rigido: 80.0}
posicoes_rodas:
  FL:
    x: 0.0
    eixo: [0.345, 0.3, 0.21]
    abracadeira: [0.1875, 0.1845, 0.357]
    vertice: [0.24262499999999998, 0.22492499999999999, 0.46199999999999997]
    haste_superior: 0.12529144523869135
    haste_inferior: 0.22767937159523252
  FR:
    x: 0.0
    eixo: [0.345, -0.3, 0.21]
    abracadeira: [0.1875, -0.1845, 0.357]
    vertice: [0.24262499999999998, -0.22492499999999999, 0.46199999999999997]
    haste_superior: 0.12529144523869135
    haste_inferior: 0.22767937159523252
  RL:
    x: 0.0
    eixo: [-0.345, 0.3, 0.21]
    abracadeira: [-0.1875, 0.1845, 0.357]
    vertice: [-0.24262499999999998, 0.22492499999999999, 0.46199999999999997]
    haste_superior: 0.12529144523869135
    haste_inferior: 0.22767937159523252
  RR:
    x: 0.0
    eixo: [-0.345, -0.3, 0.21]
    abracadeira: [-0.1875, -0.1845, 0.357]
    vertice: [-0.24262499999999998, -0.22492499999999999, 0.46199999999999997]
    haste_superior: 0.12529144523869135
    haste_inferior: 0.22767937159523252
colisao_raios:
- [0.07, -0.0, 0.006]
- [0.07644477849576774, -0.007978435982885954, 0.0059265]
- [0.08258887257655542, -0.01608159589510614, 0.0058485]
- [0.08791903532165571, -0.024541426774119333, 0.005772]
- [0.09243416074420613, -0.033389883610373185, 0.005697]
- [0.09606555780082313, -0.04238406073533679, 0.005625]
- [0.098917507560904, -0.051627735742898015, 0.0055544999999999995]
- [0.10096579499382605, -0.06084079750681035, 0.005487]
- [0.10229886073486026, -0.0701488752037385, 0.005421]
- [0.10294220896046369, -0.07948902574783666, 0.005356499999999999]
- [0.10293360930704883, -0.08857941112371338, 0.005294999999999999]
- [0.10232872021003046, -0.09758479912454254, 0.005234999999999999]
- [0.1011633783748061, -0.10646046437901643, 0.0051765]
- [0.09947541770701498, -0.11516680803085107, 0.0051195]
- [0.0973041096762673, -0.12366923562515036, 0.005064]
- [0.09468966025137263, -0.13193797118903883, 0.00501]
- [0.09167276219864492, -0.1399478283892634, 0.004957499999999999]
- [0.08829420045393002, -0.1476779528778797, 0.004906499999999999]
- [0.0845945076914805, -0.15511154589016277, 0.004856999999999999]
- [0.08048305783098286, -0.16245666315105298, 0.004807499999999999]
- [0.07610611597559613, -0.16947586114579605, 0.004759499999999999]
- [0.07150332638045075, -0.17616154153654184, 0.004712999999999999]
- [0.06654785929830245, -0.18271856507430592, 0.004666499999999999]
- [0.06142097249789659, -0.18892659880867135, 0.004621499999999999]
- [0.05615992359138772, -0.19478568063954171, 0.004577999999999999]
- [0.05060397530290653, -0.2004924090421951, 0.004534499999999999]
- [-0.03499999999999999, -0.06062177826491071, 0.006]
- [-0.04513191749153096, -0.06221390217256625, 0.0059265]
- [-0.05522150686683518, -0.0634832637736599, 0.0058485]
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

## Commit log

2026-08-22 Initial commit: Projeto Rover Frugal 4WD/4WS - Planejamento, Engenharia, Simulador Three.js e Simulador Python
    [RSAC_Export_Projeto e prototipação de rove.xlsx]
2026-08-22 Reengenharia técnica: fonte única de parâmetros, simulador físico e gêmeo digital
    Refaz a base de engenharia do projeto sobre uma fonte única de verdade e
    substitui os modelos com fatores de ajuste por física derivada.
    Fonte única de parâmetros
    - 00_Especificacao_Mestre/parametros_mestres.yaml passa a conter todo número
    de engenharia; config.py resolve os derivados e reexporta as constantes
    legadas; ferramentas/gerar_parametros_js.py sincroniza o protótipo 3D.
    Achados de engenharia corrigidos
    - Roda: a condição de marcha síncrona D <= 2*r_max*sin(pi/N) mostra que a roda
    Phi300 original não transpõe o degrau de 170x300 mm (alcance de 260 mm contra
    345 mm exigidos). V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
2026-08-23 Documentação R2: auditoria, requisitos rastreáveis e quatro documentos novos
    Reescreve a camada de planejamento sobre a engenharia da revisão R2 e corrige
    as divergências que a auditoria encontrou.
    Documentos novos
    - 00_Especificacao_Mestre/02_Auditoria_Tecnica: 20 achados de R1 com evidência
    reproduzível, severidade e resolução.
    - 00_Especificacao_Mestre/01_Requisitos_e_Rastreabilidade: 45 requisitos com
    método de verificação e artefato de evidência (18 verificados, 13 aguardando
    ensaio, 14 dependentes de hardware).
    - 00_Especificacao_Mestre/00_Parametros_Mestres: tabela gerada do YAML, com
    verificações automáticas de coerência.
    - 02_Engenharia/06 Síntese da Roda: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
2026-08-23 ROS 2 e Gazebo: workspace completo, malhas geradas e correção de massa
    O projeto mencionava "Webots/Gazebo" e "URDF/SDF" desde a revisão inicial, mas
    não havia URDF, mundo, malha nem pacote — e a documentação oscilava entre duas
    cadeias de ferramentas incompatíveis. Este commit implementa a simulação
    multicorpo de verdade e decide a ferramenta: ROS 2 Jazzy + Gazebo Harmonic.
    Workspace ros2_ws/ com quatro pacotes
    - rover_frugal_description: URDF/xacro escrito à mão e SEM nenhum número de
    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
    [aro_elastico.stl, bancada_degrau.sdf, caixa_organizadora.stl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]
2026-08-23 Refina o pacote ROS 2: curva do motor, sensor de contato e odometria de referência
    Três lacunas de fidelidade do primeiro corte do workspace.
    Tração por esforço, com a curva real do motorredutor
    Com interface de velocidade o ros2_control pedia rotação e o Gazebo entregava
    qualquer torque até o limite da junta: o motor simulado tinha torque de stall a
    1,53 m/s e o rover subiria escadas que o motorredutor real não sustenta — a
    margem de 1,61 calculada no dimensionamento nunca era exercida. Agora a
    interface é de esforço e o nó `tracao` converte velocidade desejada em torque
    saturado pelo que o motor consegue entregar naquela rotação e tensão, com
    queda de tensão do pack, mod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
    [rover_frugal.urdf.xacro]

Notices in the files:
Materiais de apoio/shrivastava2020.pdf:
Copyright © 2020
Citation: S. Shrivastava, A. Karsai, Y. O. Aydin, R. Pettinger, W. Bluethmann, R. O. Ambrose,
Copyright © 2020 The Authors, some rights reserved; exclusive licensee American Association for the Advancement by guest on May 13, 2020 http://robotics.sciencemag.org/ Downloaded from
